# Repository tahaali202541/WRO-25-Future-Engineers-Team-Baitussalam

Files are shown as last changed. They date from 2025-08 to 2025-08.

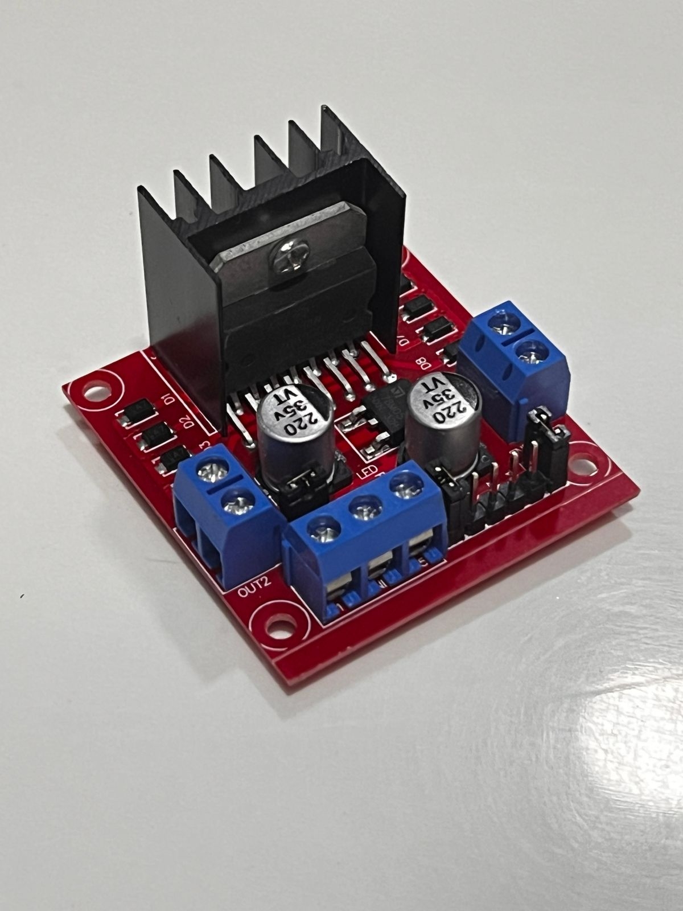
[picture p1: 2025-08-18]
Models/Electrical Components/L298N.jpg

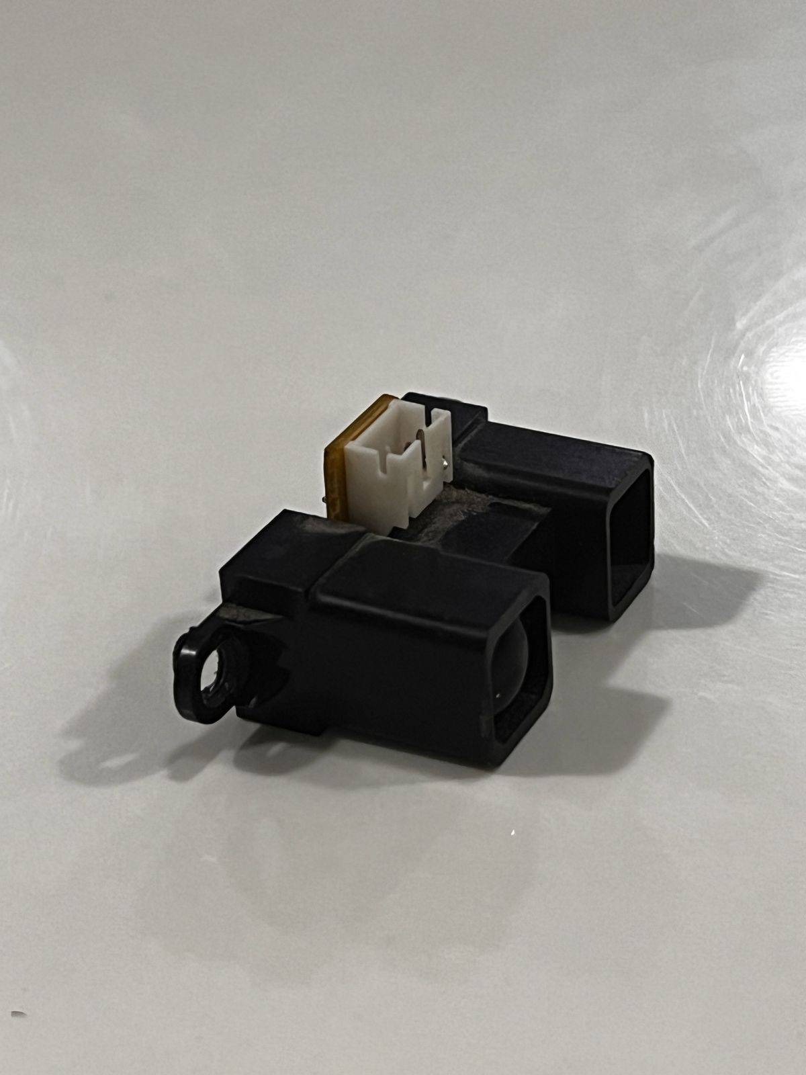
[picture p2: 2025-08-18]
Models/Electrical Components/Sharp IR sensor(Long Range).jpg

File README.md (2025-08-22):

# TEAM BAITUSSALAM
download

This repository presents our documentation of the WRO 25(Future Engineers).

# Content Table
## [TEAM INTRODUCTION](https://github.com/tahaali202541/WRO-25-Future-Engineers-Team-Baitussalam?tab=readme-ov-file#our-journey-)
1. [WHO ARE WE?](https://github.com/tahaali202541/WRO-25-Future-Engineers-Team-Baitussalam?tab=readme-ov-file#who-are-we)
2. [The Team](https://github.com/tahaali202541/WRO-25-Future-Engineers-Team-Baitussalam/blob/main/README.md#the-team)
3. [Our Goal](https://github.com/tahaali202541/WRO-25-Future-Engineers-Team-Baitussalam#our-goal)
4. [The Robot]()
5. [Our Journey](https://github.com/tahaali202541/WRO-25-Future-Engineers-Team-Baitussalam#our-journey)

## [Mobility Management](https://github.com/tahaali202541/WRO-25-Future-Engineers-Team-Baitussalam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)
1. [Motor Selection](https://github.com/tahaali202541/WRO-25-Future-Engineers-Team-Baitussalam?tab=readme-ov-file#motor-selection)
2. [Steering Mechanism](https://github.com/tahaali202541/WRO-25-Future-Engineers-Team-Baitussalam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)
3. [Chassis](https://github.com/tahaali202541/WRO-25-Future-Engineers-Team-Baitussalam?tab=readme-ov-file#chassis)
4. [Mounting](https://github.com/tahaali202541/WRO-25-Future-Engineers-Team-Baitussalam?tab=readme-ov-file#mounting)
5. [Engineering Principals](https://github.com/tahaali202541/WRO-25-Future-Engineers-Team-Baitussalam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)

## [Power and Sense Management](https://github.com/tahaali202541/WRO-25-Future-Engineers-Team-Baitussalam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)
1. [Power Source](https://github.com/tahaali202541/WRO-25-Future-Engineers-Team-Baitussalam?tab=readme-ov-file#power-source)
2. [Sensors Used](https://github.com/tahaali202541/WRO-25-Future-Engineers-Team-Baitussalam?tab=readme-ov-file#sensors-used)
3. [Wiring Diagram](https://github.com/tahaali202541/WRO-25-Future-Engineers-Team-Baitussalam?tab=readme-ov-file#wiring-diagram)
4. [Bill of Material](https://github.com/tahaali202541/WRO-25-Future-Engineers-Team-Baitussalam#bill-for-materials)

## [Obstacle Management(Open challenge round)](https://github.com/tahaali202541/WRO-25-Future-Engineers-Team-Baitussalam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)
1. [Strategy for Open Challenge round](https://github.com/tahaali202541/WRO-25-Future-Engineers-Team-Baitussalam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)
2. [Flow Diagram](https://github.com/tahaali202541/WRO-25-Future-Engineers-Team-Baitussalam#flow-diagram)
3. [Code for Open Challenge Round](https://github.com/tahaali202541/WRO-25-Future-Engineers-Team-Baitussalam#code-for-open-challenge-round)

# TEAM INTRODUCTION
## Who are we?
We are the team Baitussalam from Pakistan representing Pakistan and our Institute Baitussalam. Our team consists of three members – Taha Umer, Zulqarnain, and Sikandar.It is our first time participating in WRO. Together, we focus on different parts of the project such as coding, mechanical design, and documentation. By combining our efforts, we aim to build a functional and well-prepared robot for the Future Engineers category. 

## The Team
## Taha Umer (Team Lead)
 <br>
Age: 17  <br>
College: DOCE Baitussalam Talagang  <br>
Description: I am Taha Umer, Currently pursuing my A-levels at DOCE Baitussalam Talagang. I have been into Robotics for a long time and I think this is what makes me the "Leader". I have been to and won many robotics competitions like NERC, HSSRC, and many others. <br>

## Zulqarnain
   <br>
Age: 17   <br>
School: DOCE Jamia Baitussalam   <br>
Description: I am Zulqarnain, currently studying at the DOCE Jamia Baitussalam Talagang. I like challenges and solving maths problems is a kind of challenge for me, I am also fond of palying football.   <br>

## Sikandar

   <br>
Age: 16   <br>
School: DOCE Jamia Baitussalam   <br>
Description: I am sikandar and I am currently pursueing my O-Levels at the DOCE Baitussalam Talagang. It is my first time participating in WRO. My hobbies are programming, boxing(Not a good combination), and Robotics. I love to play football too.   <br>

## Our Goal
Our main goal is to design an autonomous robot for the WRO Future Engineers challenge, capable of navigating a course while detecting and avoiding obstacles. The main design idea is a lightweight, custom 3D-printed chassis with strategically mounted sensors (Sharp IR for long-range detection) controlled by Arduino. This setup allows the robot to accurately sense its environment, make decisions in real-time, and complete the challenge efficiently.

## The Robot

|Top|Bottom|
|-----|---|
| Top | Bottom |

|Front|Back|
|-----|---|
| Front | Back |

|Right |Left|
|-----|---|
| Right |Left |

## Our journey 
Our journey started when we were first informed about our participation in WRO 25(Future Engineers), by our management team. Our journey is not quite smooth, full of problems, mistakes, headaches, and even moments of 'Just leaving!' but what makes our jouney interesting are the moments of success, seeing the hardwork pay-off, and at last 'The Victory'. This repository not only holds the designs, codes, and components but it also holds our feelings of our way through all the stages, 'THE NATIONAL CHAMPIONSHIP' and One day 'INTERNATIONAL CHAMPIONSHIP' too.<br>
# THE HURDLES <br>
1. STEERING MECHANISM <br>
Eveyting seems too easy and simple until you are hands-on with it. Although, it was not our first time participating in any robotics competition, we have partipated in many national competitions before such as NERC(For the last 4 years), Headstarts, Air university and many other but this competition hit different. Speaking faithfully, the journey had just barely begun that 'The Steering Mechanism' stood tall infront of us. We had thought of using 'Ackerman Steering Mechanism' which first seemed easy but after working on many protytypes we changed our mind and decided to use the simple 'Parallel Steering Mechanism' made with Lego Blocks, the story does not end here — the Parallel Steering Mechanism turned out to be unnecessary and offered no real benefit. Than at last, after a lot of research we finally dediced to use "Anti Akerman Steering Mechanism".

2. The Pulley<br>
Just the first problem had finished that that the pulley said "Me too". After a few tests the The rod of pulley started making unnatural sounds and eventually the problem became inevatble. The pulley led us to get a duplicate of our base — a better one. and we had to change the whole of the mechanism.<br>

 We faced many problems, but a solution was always there just hiding behind our patience. <br>

Now the National Championship is just a few days ahead and our team is full of hope. May Allah make us able of achieving what our hardwork and sacrifice really deserves. I mean the "The National Championship". It does not matter wheter you lose or win what matters is what you learnt, your hardwork. Therefore it is said, "It is not always about the destination, but the journey that you take"

NATIONALS HERE WE COME!!!

# Mobility Management
## Motor Selection
| MOTOR | Specification |
|---|---|
|  | • Type = DC Gear Motor with Encoder <br> • 280 RPM (GA25-370) Voltage: 6–12V DC (12V typical) <br> • Speed: 280 RPM @ 12V <br> • Gear Ratio: ~1:30 <br> • Torque: ~1.5–3 kg·cm @ 12V <br> • Current: No-load 100–200 mA, stall ~2 A <br> • Encoder: 2-channel, ~330 pulses per output shaft revolution <br> • Shaft: 4 mm D-shaft <br> • Size: 25 mm diameter, ~50–60 mm length (with encoder)  |

## The reason for selection
We're using this DC gear motor with an encoder because it's the perfect tool for precise movement. The gear motor itself gives us a lot of power in a small package, while the built-in encoder acts like a digital eye, letting the robot know exactly how far and how fast its wheels are turning. This real-time feedback is crucial for tasks like accurate navigation and maintaining a steady speed, which are a big part of the challenge.

| MOTOR |  Specification |
|---|---|
|  | • Model: MG996R <br> • Type: High Torque Digital Servo Motor <br> • Operating Voltage: 4.8V - 7.2V (often listed as 5V) <br> • Stall Torque (at 6V): Approximately 10 kg·cm to 13 kg·cm (kilogram-force per centimeter) <br> • Operating Speed (at 6V): Around 0.16 sec/60° <br> • Gear Material: Metal gears <br> • Dimensions: Approximately 40.7mm x 19.7mm x 42.9mm <br> • Weight: Around 55g <br> • Rotation: 0° to 180° |

## The reason for selection
We chose this servo motor for its robust performance and durability. Its high torque and metal gears are essential for the demanding tasks of our robot, while its affordability and availability make it a practical and reliable choice for our project's development.

# Steering Mechanism
## Anti-Ackerman Steering Mechanism

 <br>
Anti-Ackermann steering is a geometry where the outer wheel turns more than the inner wheel, opposite of standard Ackermann. In the context of WRO, it can be suitable for robots designed with a focus on speed. This mechanism helps reduce tire scrub and rolling resistance, allowing the robot to accelerate faster and move more efficiently in straight runs. It also provides better stability during high-speed turns, as the slip angle of the outer wheel improves grip. While it sacrifices some low-speed precision, Anti-Ackermann steering can be advantageous in speed-oriented designs where covering distance quickly is the main priority.

# Chassis

Our chassis is a mixture of components made of (Previous design)-(3D designs made by PETG as well as PLA), and also Acryllic sheet especally designed for stability and modularity. It features a rear-wheel drive system powered by DC gear motors for consistent motion. For steering, we implemented a parallel steering mechanism driven by the MG996R servo, ensuring precise and predictable turns. All sensors are strategically mounted to provide optimal track visibility, and the overall design maintains a low center of gravity for balanced performance.

- Material: lightweight and strong usnig parts made with PETG and PLA, Lego blocks, and Acrallyic sheet

| PETG | Specifications |
|---|---|
| istockphoto-2169621495-612x612 | • Definition: A thermoplastic combining the easy printing of PLA with the strength of ABS. <br> • Key Properties: Strong, durable, slightly flexible, and more heat/chemical resistant than PLA. <br> • Advantages: Good for mounts and moving parts, excellent layer adhesion, less warping than ABS. <br> • Limitations: Can string during printing, heavier and softer than PLA. <br> • Print Settings: Nozzle 230–250 °C, Bed 70–80 °C. |

| PLA | Specifications |
|---|---|
| images | •  Definition: A biodegradable thermoplastic made from renewable resources like corn starch. <br> • Key Properties: Easy to print, lightweight, good surface finish, but brittle. <br> • Advantages: Low warping, ideal for prototypes and lightweight robot parts. <br> • Limitations: Low heat resistance, weaker under stress compared to PETG/ABS. <br> • Print Settings: Nozzle 190–220 °C, Bed 20–60 °C. |

| Arcylic Sheet | Specifications |
|---|---|
| images (1) | •  Definition: Acrylic (PMMA) is a lightweight, transparent plastic often used as a glass substitute. <br> • Key Properties: Rigid, smooth, lightweight, and visually clear. <br> • Usage in Our Robot: We used acrylic sheets for both the upper and lower decks to provide a stable, flat surface for mounting components. <br> • Advantages: Easy to cut, lightweight, gives a neat look, and provides good electrical insulation. <br> • Limitations: Brittle compared to PETG/PLA (can crack under heavy stress). |

- Shape: rectangular stability
- Size: fits robot components and competition rules
- Motor & wheel mounting: securely attached with brackets/screws
- Component placement: Arduino, sensors, battery positioned for balance
- Stability: reinforced to prevent tipping or bending
- Easy maintenance: components are accessible for troubleshooting

# Mounting

- All components securely fixed on the chassis using screws, nuts, and 3D-printed brackets
- Raspberry Pi mounted centrally for balance; camera at front for clear view (Removed Later)
- Sensors placed near center of gravity for accuracy
- Motors aligned with wheels 
- Wires routed to avoid interference with moving parts
- Components accessible for easy maintenance and troubleshooting <br>
 Link for all the mounts and components-> [(Models)](https://github.com/tahaali202541/WRO-25-Future-Engineers-Team-Baitussalam/tree/main/Models)

# Engineering Principals

1. Wheel RPM from motor:
Wheel_RPM = Motor_RPM / Gear_Ratio

2. Robot linear speed:
v = (2 * π * Wheel_radius * Wheel_RPM) / 60

3. Wheel torque:
Wheel_Torque = Motor_Torque * Gear_Ratio

4. Force at wheels:
F = Wheel_Torque / Wheel_radius

5. Mechanical power:
P = Torque * Angular_speed
P = F * v

6. Motor electrical power:
P_elec = P_mech / Motor_efficiency
I = P_elec / Voltage

# Power and Sense Managemnet
## POWER SOURCE
| Battery | Specifications |
|---|---|
| | •  Brand	JSUMO <br> • Capacity(mAh)	450 mah <br> • Voltage(V)	11.1V (Full Charge 12.6V) <br> • Discharge Rate (C)	25 <br> • Max Burst discharge Rate (C)	50 <br> • Cell Configuration	3S1P (3 Serial, 1 Parallel) <br> • Net <br> • Weight	46.5 grams <br> • Length	40.2mm <br> • Width	24.3mm <br> • Height	24.2mm |

Reason for Selection : 

## Sensors Used

| Sharp IR sensor(Long Range) | Specifications |
|---|---|
| | • Model: Sharp GP2Y0A02YK0F (Long Range IR Sensor) <br> • Detection Range: 20 cm – 150 cm <br> • Output Type: Analog voltage (distance → voltage curve, non-linear) <br> • Operating Voltage: 4.5V – 5.5V (typ. 5V) <br> • Current Consumption: ~33 mA (typical) <br> • Response Time: ~39 ms <br> • Output Voltage Range: ~2.8V (near) to ~0.4V (far) <br> • Dimensions: ~29.5 × 13 × 21.6 mm <br> • Applications: Obstacle detection, distance measurement for navigation, wall following |

Reason for Selection : We chose The Sharp IR long-range sensor for its reliable distance detection range of 20–150 cm, low power consumption, and compact size. Its stable analog output makes it easy to interface with Arduino or Raspberry Pi, and it performs more consistently than ultrasonic sensors on reflective or angled surfaces, making it well-suited for obstacle avoidance in our robot.

## Wiring Diagram
visual circuit diagram

## Bill for Materials

| Category | Components | Total Price |
|---|---|---|
| Power Supply  | • Battery <br> • Buck Convertor(320 Rs) | RS 320 |
| Motors | • DC Motor(2300 Rs) <br> • Servo Motor(Rs 900)| RS 3200 |  
| Sensors | Sharp IR sensors(Long Range)(1300 Rs) | Rs 1300 |
| Electrical Parts | Ardino Nano(800 Rs) <br> • L298(370 Rs) | Rs 1170 |
| Mechanical Parts | Tyres, Gears, Chassis, Steering, Screws, Nuts, etc | Rs 140000 |
| All the Components | Total Price | Rs 19990 (Without The Components that were burnt) |

# Obstacle Management(Open challenge round)

## Strategy for Open Challenge round

Open Challenge Round, which is simpler and easier than The Obstacle avoiding Round and does not need very big algorithms, so we decided to use a very simple 'Strategy'. For the Open Challenge round we are using PD for keeping our Robot at a specific distance from the outer and the inner walls, using the IR sensors. The IR sensors help the Robot mantain a safe distance from the inner and outer boundaries. The IR sensor sends data to the Arduino Nano and than the Arduino using PD sets the direction via Servo Motor.

## Flow Diagram



## Code For Open Challenge Round

## HARD CODE

Our coding for the Robot started from writing a hardcode for three laps. It's main purpose was to know our Robot's directions and precesion. It also helped us in knowing the exact figures of the sensor values and servo' direction. 

#include <Servo.h> <br>

Servo myservo;<br>

int M_1 = 9;<br>
int M_2 = 10;<br>
int S1 = 11;<br>
int counter=0;<br>

void setup() {<br>
  pinMode(M_1,OUTPUT);<br>
  pinMode(M_2,OUTPUT);<br>
  pinMode(S1,OUTPUT);<br>

 myservo.attach(3);  <br>

}

void loop() {   <br>
  counter++;<br>
//first turn<br>
myservo.write(71.5);<br>
 delay(300);<br>
 forward(255);<br>
 delay(530);<br>
 myservo.write(120);<br>
 delay(200);<br>
 forward(255);<br>
 delay(550);<br>

//second turn<br>
 myservo.write(71.5);<br>
 delay(300);<br>
  forward(255);<br>
 delay(500);<br>
 myservo.write(120);<br>
 delay(200);<br>
forward(255);<br>
delay(550);<br>
//third turn<br>
myservo.write(71.5);<br>
 delay(300);<br>
 forward(255);<br>
 delay(530);<br>
 myservo.write(120);<br>
 delay(200);<br>
forward(255);<br>
delay(550);<br>
//fourth turn<br>
myservo.write(71.5);<br>
 delay(300);<br>
 forward(255);<br>
 delay(530);<br>
 myservo.write(120);<br>
 delay(200);<br>
forward(255);<br>
delay(550);<br>
  Stop();<br>
  while(1);<br>
}<br>

void forward(int pwm){<br>
  analogWrite(S1,pwm);<br>
  digitalWrite(M_2,HIGH);<br>
  digitalWrite(M_1,LOW);<br>
}<br>

void backward(int pwm){<br>
analogWrite(S1,pwm);<br>
  digitalWrite(M_2,LOW);<br>
  digitalWrite(M_1,HIGH);<br>
}<br>
void Stop(){<br>
  digitalWrite(M_1,LOW);<br>
  digitalWrite(M_2,LOW);<br>
}<br>

## PD Control

The second part of our coding journey was the PD control. We used it for keeping our Robot at a distance from both the boudaries

#include <Servo.h><br>
Servo myservo;                                     /////Servo Related<br>

int M_1 = 9;<br>
int M_2 = 10;                     /////Motor Pins<br>
int S1 = 11;<br>

double kp = 1.5;<br>
double kd = 10;<br>

double  BaseAngle = 71.5;                    ///////////Wall Following Related<br>
double MinAngle = 20;<br>
double MaxAngle = 120;<br>

int lastError = 0;<br>

#define front_value  AnDg(0)<br>
  #define right_value AnDg(1)                      ///Semnsor Related<br>
  #define left_value  AnDg(2)<br>

int error = 0;<br>

void setup() {<br>
  pinMode(M_1,OUTPUT);<br>
  pinMode(M_2,OUTPUT);<br>
  pinMode(S1,OUTPUT);<br>

myservo.attach(3); <br>

 Serial.begin(9600);<br>

}<br>

void loop() {<br>   
  
unsigned int position = AnDg(1);<br>

  int error = position - 100;<br>
  
 int derivative = error - lastError;<br>
 lastError = error;<br>

  int AngleChange = kp * error+ kd * (derivative);<br>

int Rotate =  BaseAngle - AngleChange;<br>
 if (Rotate> MaxAngle ) {Rotate = MaxAngle; }<br>
 if (Rotate< MinAngle ) {Rotate = MinAngle; }<br>

MotorControl(200,Rotate);<br>

}<br>

void MotorControl(int pwm ,int ServoUpdate){<br>

   myservo.write(ServoUpdate);<br>

   analogWrite(S1,pwm);<br>
   digitalWrite(M_2,HIGH);<br>
   digitalWrite(M_1,LOW);<br>

}<br>

void forward(int pwm){<br>
  analogWrite(S1,pwm);<br>
  digitalWrite(M_2,HIGH);<br>
  digitalWrite(M_1,LOW);<br>
}<br>

void backward(int pwm){<br>
analogWrite(S1,pwm);<br>
  digitalWrite(M_2,LOW);<br>
  digitalWrite(M_1,HIGH);<br>
}<br>
void Stop(){<br>
  digitalWrite(M_1,LOW);<br>
  digitalWrite(M_2,LOW);<br>
}<br>
int AnDg(int x){<br>
  if(  x==0)<br>{return((map(analogRead(A0),0,1024,0,255)+map(analogRead(A0),150,600,0,255))/2);}<br>
 else if(  x==1)<br>{return((map(analogRead(A1),0,1024,0,255)+map(analogRead(A1),150,600,0,255))/2);}<br>
 else if(  x==2)<br>{return((map(analogRead(A2),0,1024,0,255)+map(analogRead(A2),150,600,0,255))/2);}<br>
}<br>

# A MESSAGE OF THANKFULLNESS

At last, I would like to thank the organization and our department for giving us such a great opportunity for partiticpating in WRO 25. This competition helped us a lot in building ourself in many fields. Special Thanks our mentors, institute, and friends for their guidance and support throughout this project.

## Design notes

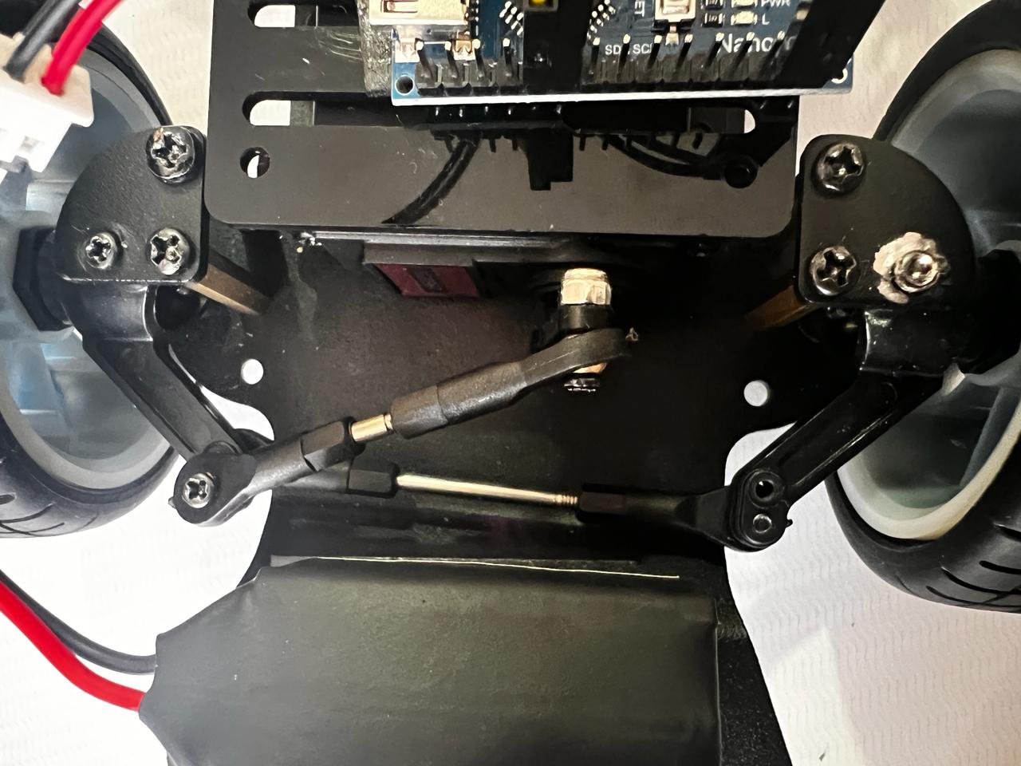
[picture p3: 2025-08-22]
Robot Photos/Steering Mechanism.jpg

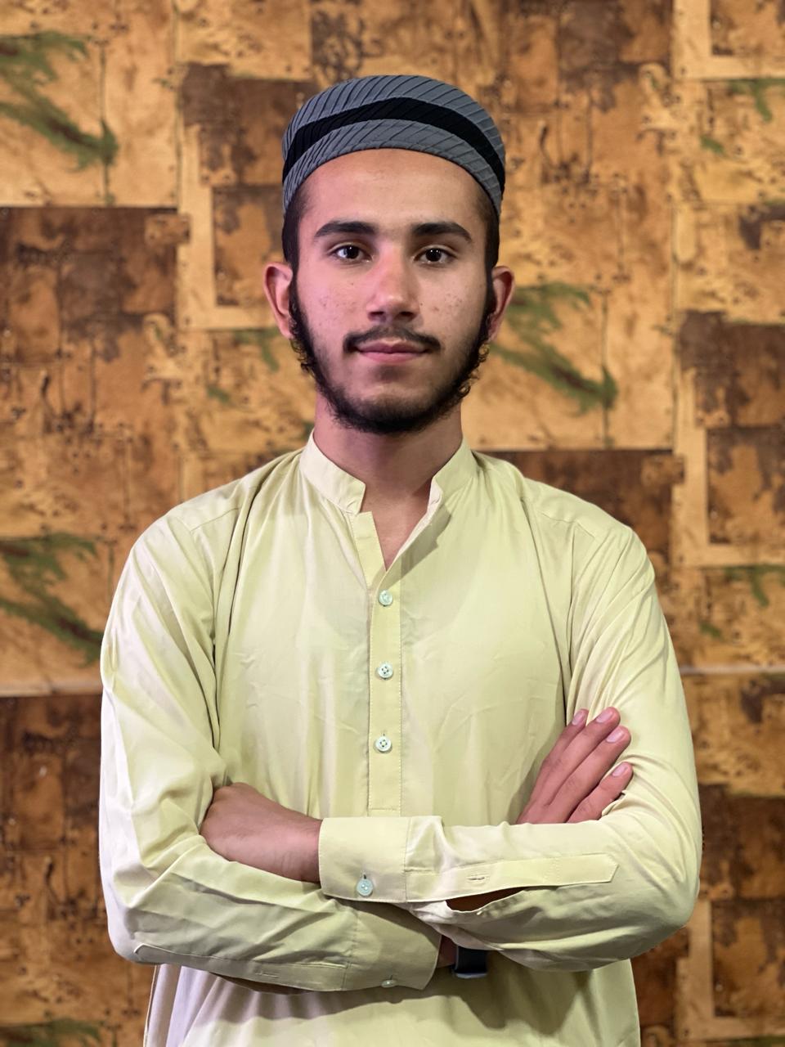
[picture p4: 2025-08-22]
Team Photos/Zulqarnain.jpg

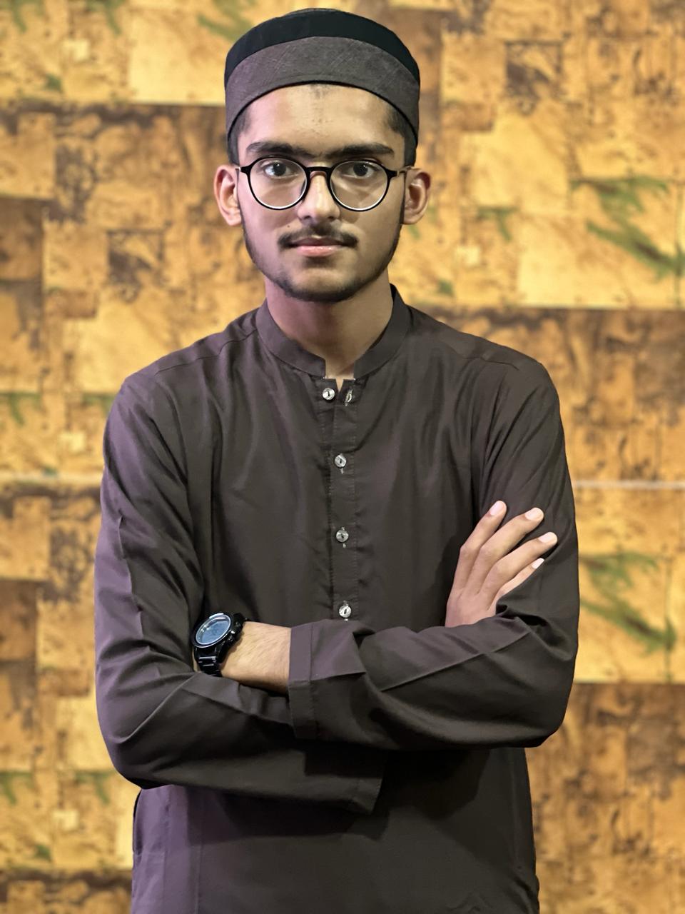
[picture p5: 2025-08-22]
Team Photos/Taha Umer.jpg

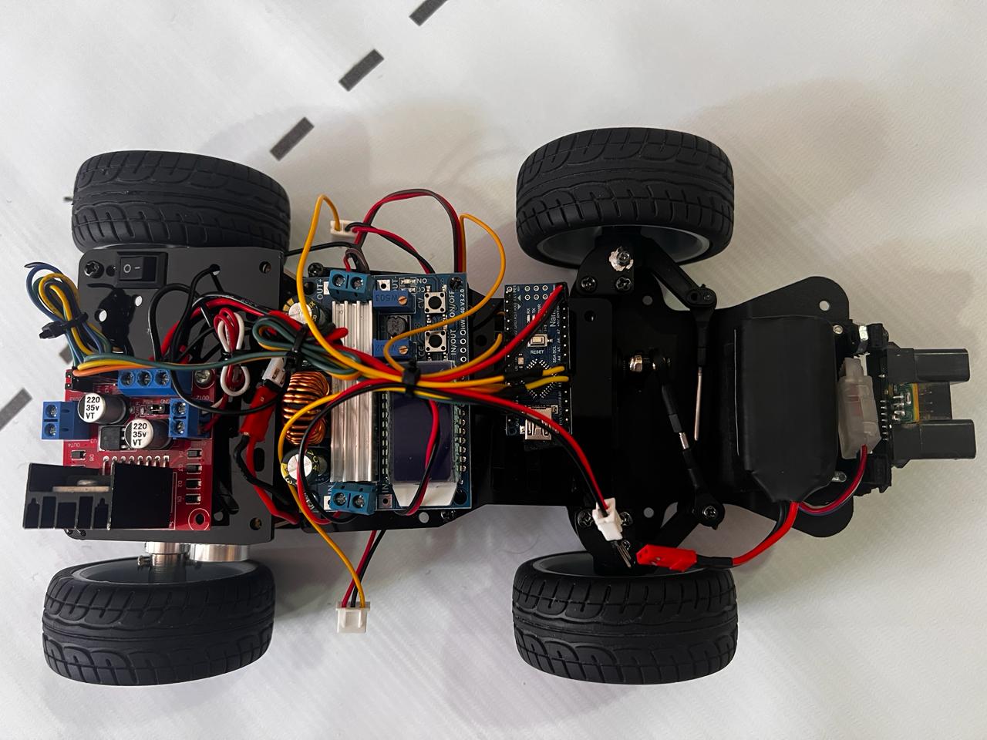
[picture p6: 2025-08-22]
Robot Photos/Top.jpg

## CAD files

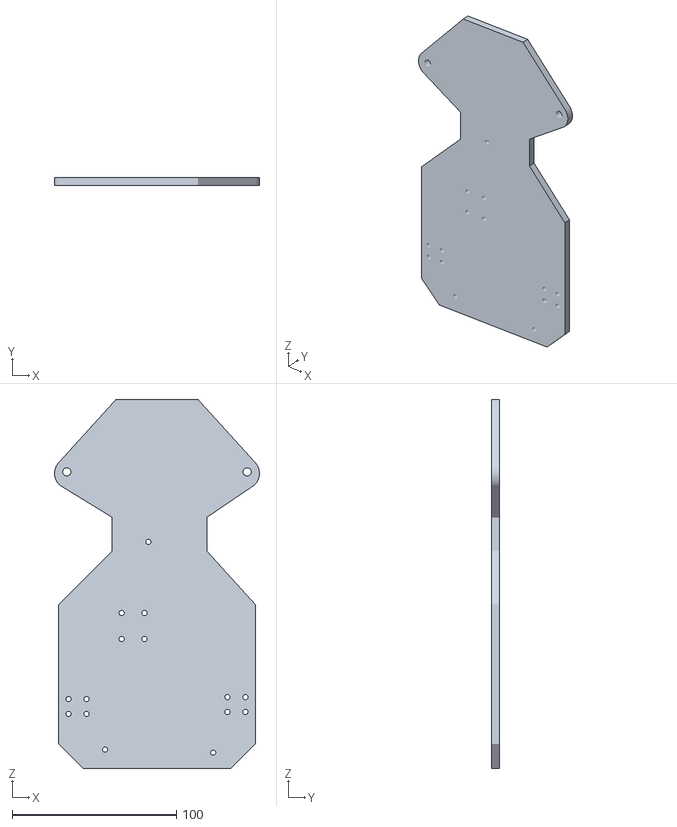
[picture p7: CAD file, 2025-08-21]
Models/3D designs/Main base 1.STL
125.0 x 5.00 x 225.0

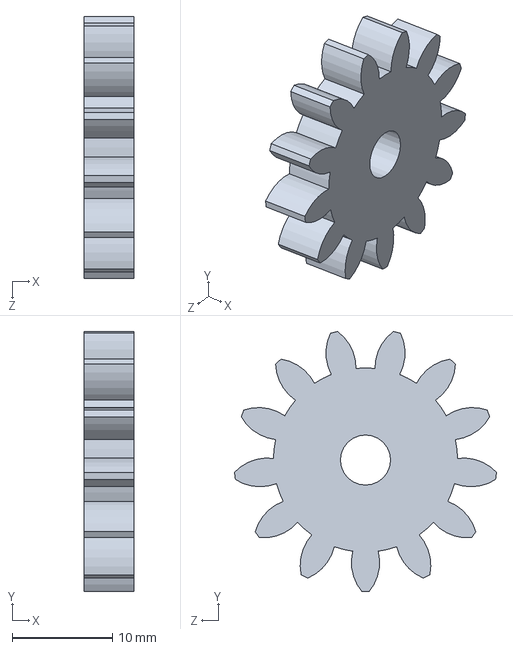
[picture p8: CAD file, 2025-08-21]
Models/3D designs/13teeth.SLDPRT
5.00 x 25.9 x 26.1 mm

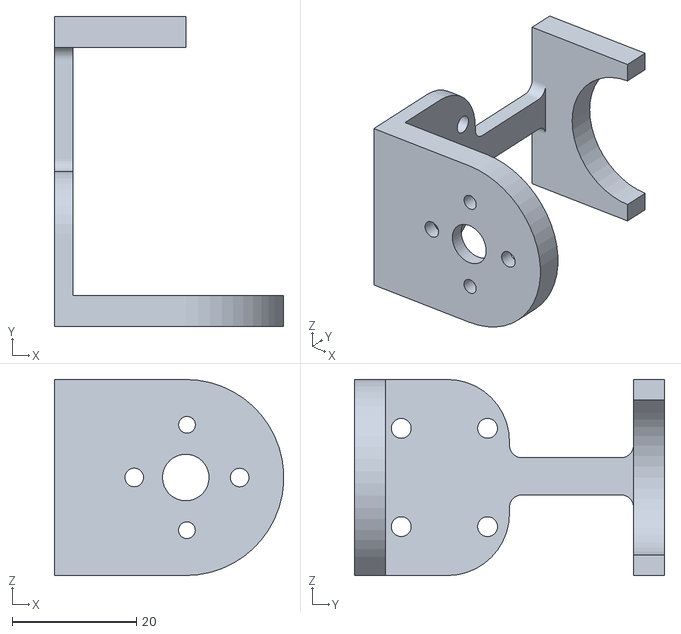
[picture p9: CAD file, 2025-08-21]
Models/3D designs/motor mount.STL
37.0 x 50.0 x 31.6

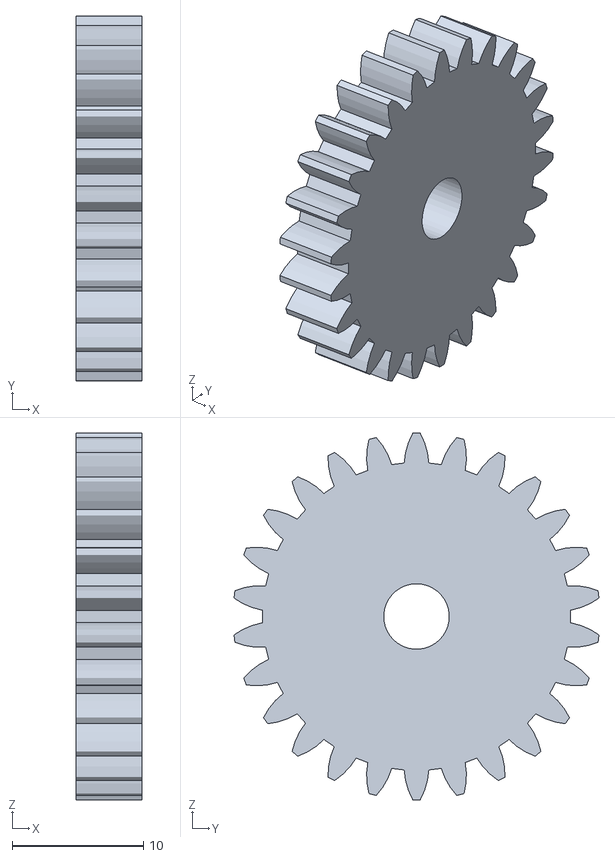
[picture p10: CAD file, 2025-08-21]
Models/3D designs/spur gear_iso bigger.STL
5.00 x 27.9 x 28.0

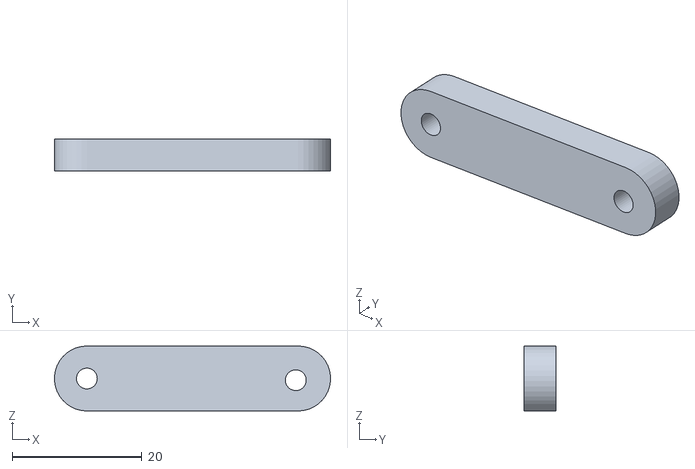
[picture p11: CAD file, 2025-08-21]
Models/3D designs/part 3.STL
42.5 x 5.00 x 10.0

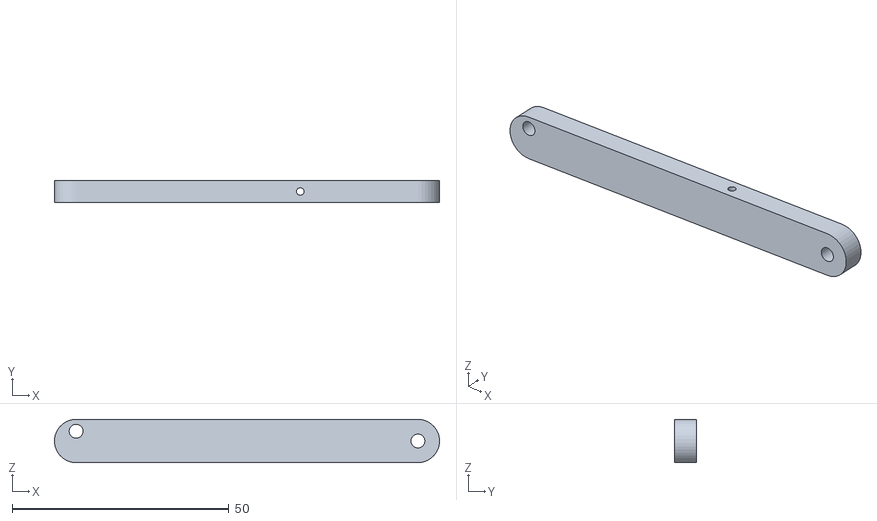
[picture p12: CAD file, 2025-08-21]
Models/3D designs/tie rod 1.STL
88.9 x 5.00 x 10.0

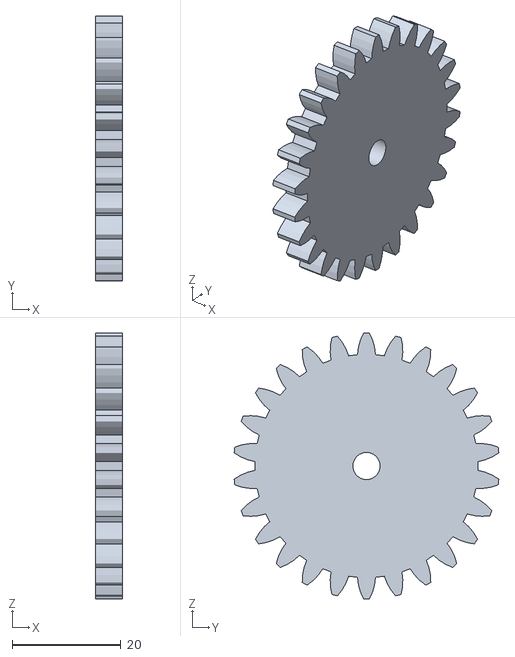
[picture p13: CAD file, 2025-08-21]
Models/3D designs/26teeth.STL
5.00 x 48.8 x 49.0

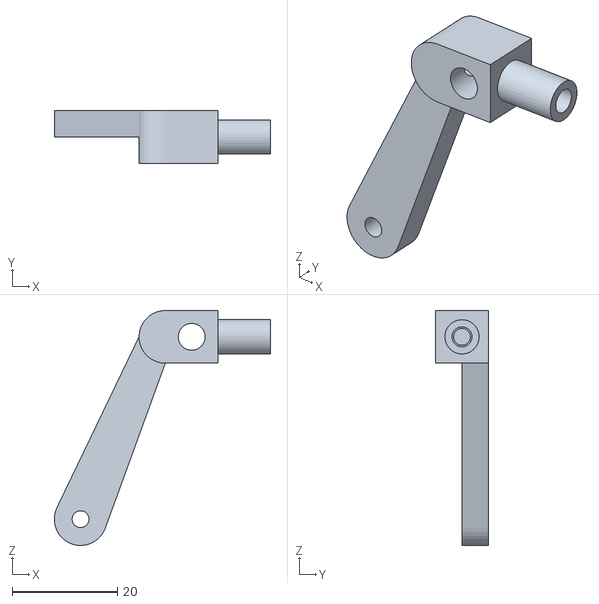
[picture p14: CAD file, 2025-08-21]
Models/3D designs/steering arm 110 left.STL
41.1 x 10.0 x 44.6

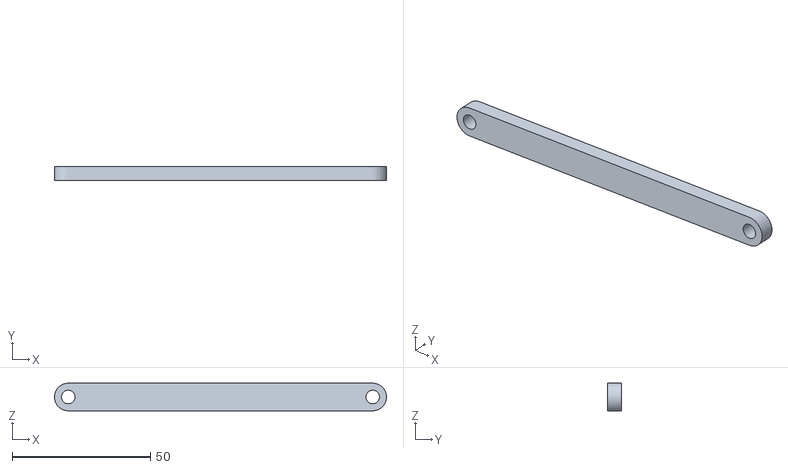
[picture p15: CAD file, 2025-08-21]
Models/3D designs/part 1.STL
120.0 x 5.00 x 10.0

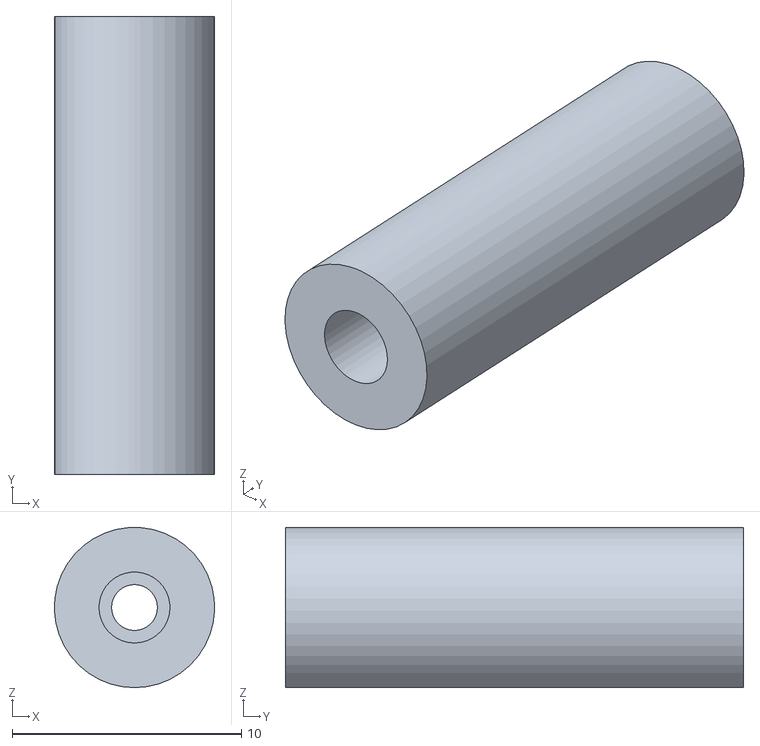
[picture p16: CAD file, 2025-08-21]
Models/3D designs/servo rod 1.STL
6.99 x 20.0 x 7.00

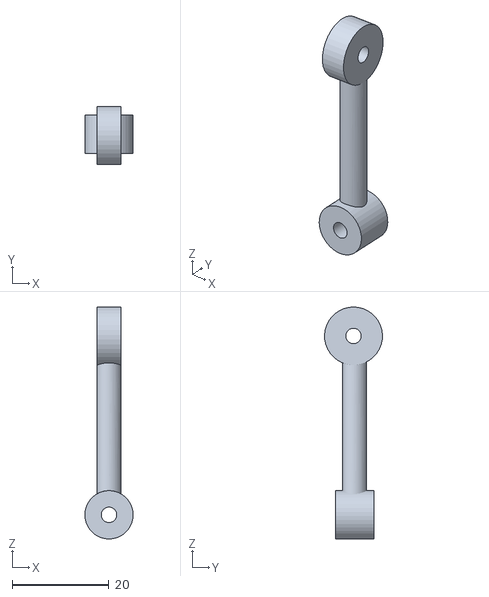
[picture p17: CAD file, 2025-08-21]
Models/3D designs/Part1 for second ackerman 1.STL
9.99 x 12.0 x 48.0

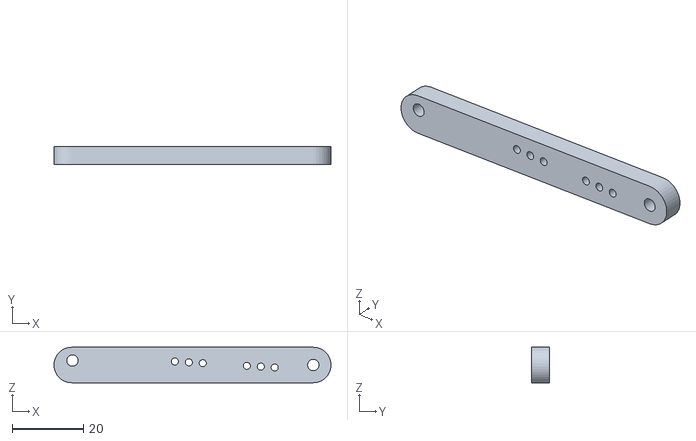
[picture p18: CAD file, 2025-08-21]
Models/3D designs/part 4.STL
78.0 x 5.00 x 10.0

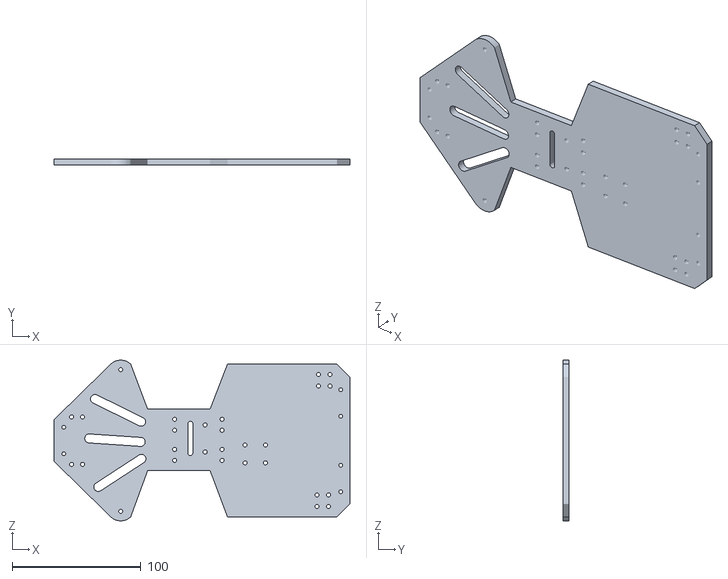
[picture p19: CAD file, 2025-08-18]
Models/3D designs/First deck (1).STL
230.0 x 5.00 x 124.9

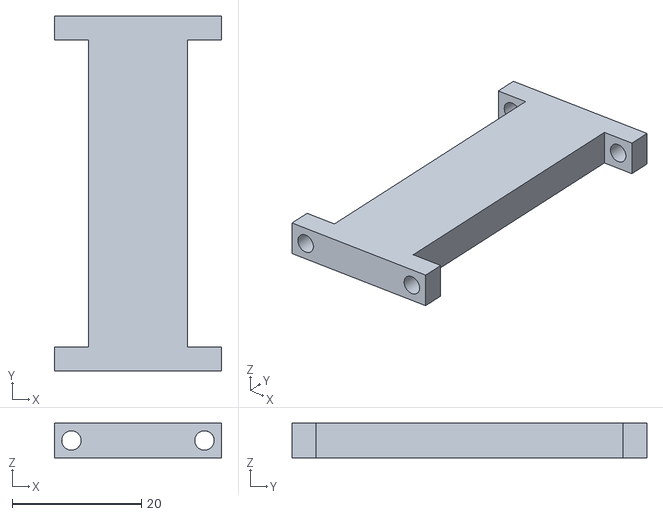
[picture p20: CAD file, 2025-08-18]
Models/3D designs/Base support (1).STL
25.9 x 55.0 x 5.40

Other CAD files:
Models/3D designs/2nd steering arm connector.SLDPRT
Models/3D designs/second deck (1).STL
Models/3D designs/Sharp IR sensor mount (2).STL
Models/3D designs/Motor Mount (1) (2).STL

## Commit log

2025-08-21 Changed the design of the Robot
    [pulley rod mount (1).STL]
2025-08-21 Flow daigram
